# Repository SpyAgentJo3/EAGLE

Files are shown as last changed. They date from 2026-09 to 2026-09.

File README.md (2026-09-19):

# EAGLE
This repository contains all information and project files having to do with EAGLE a system designed for recovery and aerodynamic control of suborbital student rockets. EAGLE contains of a self-developed PCB and the mechanical design for a 16cm diameter rocket 

## Repository Structure

The repository is organized into the following main directories:

```text
├── ARCHER
│   ├── CAD Design
│   ├── Documentation
│   │   ├── Circuit Drawing
│   │   ├── Mechanical Design
│   │   ├── PCB
│   │   └── Software
│   ├── PCB Design
│   │   ├── CanSat Shield - Landesysteme v1.0.0
│   │   ├── EAGLE Recovery v1.0.0
│   │   ├── Footprint Library
│   │   ├── KiCAD 3D Models
│   │   ├── PCB Concept v2.0.0
│   │   └── Symbol Library
│   ├── Pyrochannels
│   ├── Simulation
│   ├── Software
│   │   └── EAGLE v1.2.1
│   │       ├── src
│   │       └── test
│   └── Misc
```

The repository contains the following main areas:

- **CAD Design** – CAD models and mechanical design files
- **Documentation** – Technical documentation, circuit diagrams, PCB documentation, and software-related documentation
- **PCB Design** – PCB layouts, libraries, concepts, recovery versions, and related design files
- **Pyrochannels** – Design files and backups related to the pyrochannel system
- **Simulation** – Simulation models and related files
- **Software** – Source code and tests for the project software
- **Misc** – Additional files that do not belong to the other categories

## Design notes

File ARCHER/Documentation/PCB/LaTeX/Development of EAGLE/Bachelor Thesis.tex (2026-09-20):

\documentclass[fontsize=11pt,%
twoside,% oneside als Alternative m\"{o}glich
BCOR          = 8mm, % bei Bedarf anzupassen
DIV           = 11,  % kann nach Belieben geändert werden
titlepage     = off,%
index=totoc,%
xcolor        = pdftex,%
dvipsnames,%
bibliography  = totoc,%
bibliography = numbered, % bei Bedarf einschalten
listof        = notnumbered]{scrreprt}

\usepackage[left=3.5cm,right=2cm,top=2.5cm,bottom=2cm]{geometry}
\usepackage[english]{babel}                         %deutsches Sprachpacket
\usepackage[utf8]{inputenc}                         %input utf8
\usepackage[official]{eurosym}                      %Symbolsatz
\usepackage{amsmath}                                %Mathepacket
\usepackage{siunitx}                                %Package für zwei nachfolgende Befehle
\sisetup{locale=UK}
\sisetup{per-mode=fraction}
\usepackage{graphicx}                               %Bilder einfügen
\usepackage{subfigure}                              %Subfigures erstellen
\usepackage{subcaption}
\usepackage[onehalfspacing]{setspace}               %für Abstände
\usepackage{booktabs}                               %Für Ruler in Tabellen
\usepackage{makecell}
\usepackage{caption}
\usepackage{tabulary}
\usepackage{tabularx}
\usepackage{array}
\usepackage[table]{xcolor}
\definecolor{light grey}{RGB}{182,182,182}
\usepackage{rotating}
\usepackage{tablefootnote}
\usepackage{refcount}
\usepackage{hhline}
\usepackage{adjustbox}
\usepackage{subcaption}
\usepackage{float}
\usepackage{acronym}
\usepackage{listings}
\definecolor{codegreen}{rgb}{0,0.6,0}
\definecolor{codegrey}{rgb}{0.5,0.5,0.5}
\definecolor{codepurple}{rgb}{0.58,0,0.82}
\definecolor{backcolour}{rgb}{0.95,0.95,0.92}
\definecolor{codeblue}{rgb}{0.0,0.4,0.8}
\lstset{
	language=C++,                       % Sprache auf C++ setzen
	backgroundcolor=\color{backcolour}, % Hintergrundfarbe
	commentstyle=\color{codegreen},    % Farbe für Kommentare (z.B. // )
	keywordstyle=\color{codeblue}\bfseries, % Farbe für Keywords (int, auto, void, ...)
	numberstyle=\tiny\color{codegrey},  % Stil der Zeilennummern
	stringstyle=\color{codepurple},     % Farbe für Strings ("Text")
	basicstyle=\ttfamily\small,         % Festbreitenschriftart für den Code
	breakatwhitespace=false,            
	breaklines=true,                    % Automatische Zeilenumbrüche bei langen Zeilen
	captionpos=b,                       % Beschriftung unter dem Codeblock
	keepspaces=true,                    
	numbers=left,                       % Zeilennummern links anzeigen
	numbersep=5pt,                      % Abstand der Nummern zum Code
	showspaces=false,                
	showstringspaces=false,
	showtabs=false,                  
	tabsize=4,                          % Tabulatorbreite
	frame=single,                       % Rahmen um den Codeblock
	rulecolor=\color{gray!30}           % Farbe des Rahmens
}
\usepackage{accents}
\usepackage[stable]{footmisc}
\usepackage{pdfpages}
\usepackage[
backend=biber,
style=numeric,
sorting=none
]{biblatex}
\DefineBibliographyStrings{english}{
	bibliography = {References}
}
\addbibresource{mybibFile.bib} %Import the bibliography file
\counterwithin{figure}{section}
\counterwithin{table}{section}
\counterwithin{equation}{section}

\begin{document}

\begin{titlepage}
	\centering

	\begin{center}
	\captionsetup{font=footnotesize}
	\begin{figure}[!h]
		\subfigure{}
        \hspace{0.5cm}
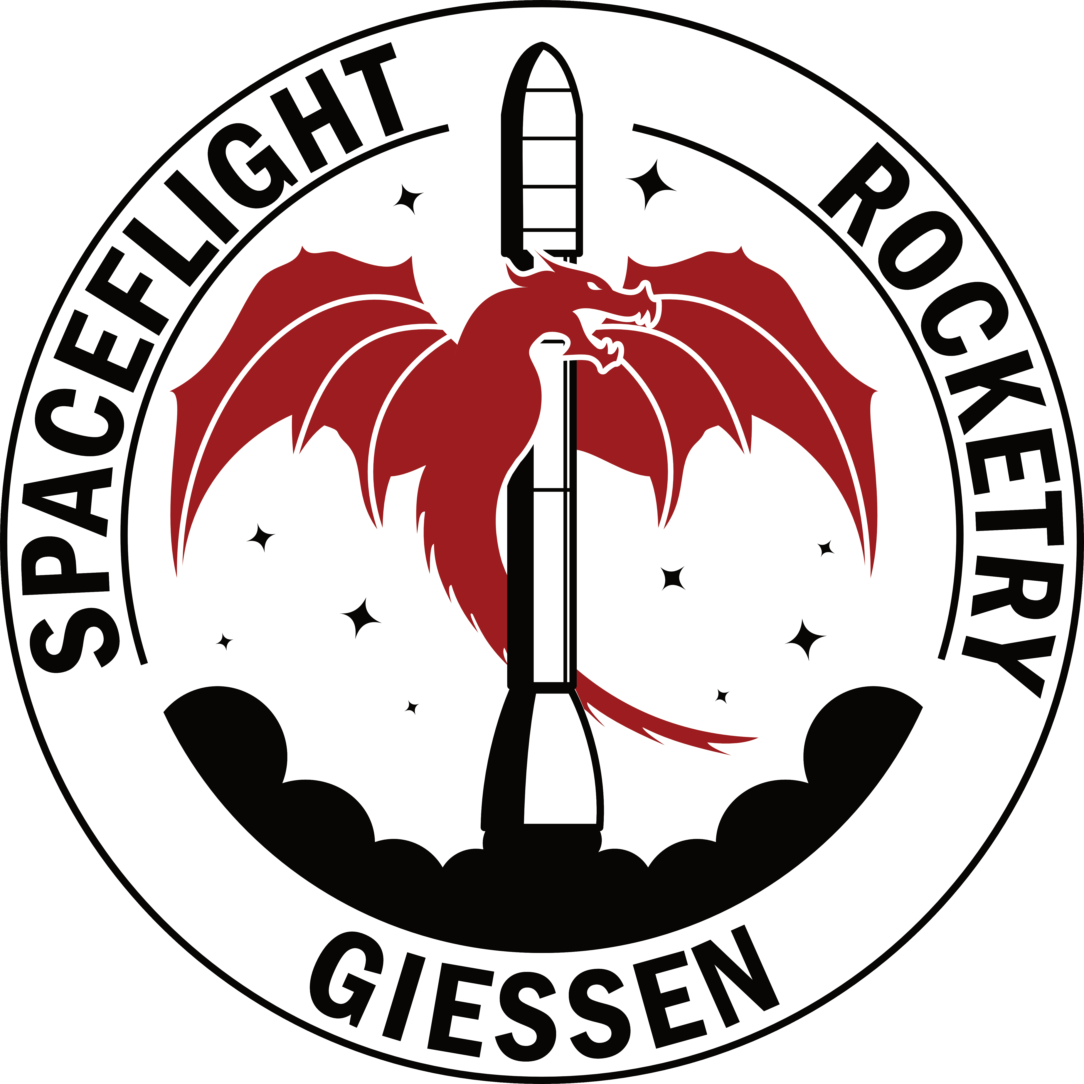
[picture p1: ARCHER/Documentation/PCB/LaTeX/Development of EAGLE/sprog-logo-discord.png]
		\subfigure{}
    \end{figure}
    \end{center}

	{\scshape\LARGE Technische Hochschule Mittelhessen \\ und \\ Spacelfight Rocketry Gießen e.V.\par}
	\vspace{1cm}
	{\scshape\Large Projektarbeit\par}
	\vspace{1cm}
	{\huge\bfseries Development of the Electronic Actuaion \& Guidance for Landing and Elevation (EAGLE) system\par}
	\vspace{0.25cm}
    \rule{\textwidth}{.5pt}
    \vspace{.25cm}
    {\large\bfseries Entwicklung des Electronic Acutation \& Guidance for Landing and Elevation (EAGLE) Systems\par}
    \vspace{.3cm}
	{\Large\scshape SoSe 2025\par}
	\vspace{1cm}
	{\Large \textbf{vorgelegt von}\\ Jason Gläser\par}
	\vfill
	betreut durch\par
    Prof. Dr. Chris Volkmar
	\vfill

% Bottom of the page
	{\large \today\par}
	\cleardoublepage
\end{titlepage}

\setcounter{page}{1}
\pagenumbering{Roman}

\chapter*{Eidesstattliche Erklärung}
Hiermit versichere ich, dass ich die vorliegende Arbeit selbstständig und unter aus
schließlicher Verwendung der angegebenen Literatur und Hilfsmittel erstellt habe. Die
Arbeit wurde bisher in gleicher oder ähnlicher Form keiner anderen Prüfungsbehörde
vorgelegt und nicht veröffentlicht.\\\\

\noindent Ort, Datum: \dotfill \hspace{3mm} Unterschrift: \dotfill 

\newpage

\chapter*{Abstract}
The development of the "Electronic Actuation \& Guidance for Landing and Elevation" (EAGLE) system is a project developed in cooperation with the student rocketry association "Spaceflight Rocketry Gießen e.V." as part of its self-developed on-board computer called "Advances System for Control Electronics, Navigation and Tracking" (ASCENT). Therefore, I would like to thank Spaceflight Rocketry Gießen for giving me the opportunity to pursue the project with their equipment and funding.\\
EAGLE is a avionics module which uses real-time sensor data to accurately estimate the rockets position and attitude as well as detecting mission critical waypoints (such as apogee) to deploy the recovery system, perform the staging and subsequent firing of the sustainer's motor and make real-time decisions about an active aerodynamical airbrake system, which accurately limits the maximum altitude to a preset value.\\
The development process of a printed circuit board for this system according to the rule book provided by the "European Rocketry Challenge" will be the core subject of this project.

\newpage
\tableofcontents
\cleardoublepage

\listoffigures
\cleardoublepage

\listoftables
\cleardoublepage

\chapter*{List of abbreviations}
	\begin{acronym}
		\acro{SRPOG}[SPROG]{\dotfill Spaceflight Rocketry Giessen}
		\acro{eV}[e.V.]{\dotfill eingetragener Verein}
		\acro{EAGLE}[EAGLE]{\dotfill Electronic Acutation \& Guidance for Landing and Eleveation}
		\acro{PIPE}[PIPE]{\dotfill Project for Inital Practical Experimentation}
		\acro{ARCHER}[ARCHER]{\dotfill Aerial Rocket for Competions and High-altitude Experimental Rocketry}
		\acro{PCB}[PCB]{\dotfill Printed Circuit Board}
		\acro{PWM}[PWM]{\dotfill Power Width Modulation}
		\acro{IC}[IC]{\dotfill Integrated circuit}
		\acro{PSU}[PSU]{\dotfill Power supply unit}
		\acro{SMD}[SMD]{\dotfill Surface mounted devices}
		\acro{SPI}[SPI]{\dotfill Serial peripheral interface}
		\acro{I2C}[I2C]{\dotfill Inter-Integrated Circuit}
		\acro{UART}[UART]{\dotfill Universal Asynchronous Receiver-Transmitter}
		\acro{RAM}[RAM]{\dotfill Random access memory}
		\acro{UPDI}[UPDI]{\dotfill Unified Program and Debug Interface}
		\acro{GND}[GND]{\dotfill Ground}
		\acro{ASCENT}[ASCENT]{\dotfill Advanced System for Control Electronics, Navigation and Tracking}
		\acro{EuRoC}[EUROC]{\dotfill European Rocketry Challenge}
		\acro{COTS}[COTS]{\dotfill Commercial Off-The-Shelf}
		\acro{IMU}[IMU]{\dotfill Inertial Measurement Unit}
		\acro{JLU}[JLU]{\dotfill Justus-Liebig-University Giessen}
		\acro{THM}[THM]{\dotfill Technische Hochschule Mittelhessen}
		\acro{OSR}[OSR]{\dotfill Oversampling ratio}
		\acro{MOSFET}[MOSFET]]{\dotfill Metal-oxide-semiconductor field-effect transistor}
		\acro{ST}[ST]]{\dotfill Schmitt Trigger}
	\end{acronym}
	\cleardoublepage

\setcounter{page}{1}
\pagenumbering{arabic}

\chapter{Introduction}
"Spaceflight Rocketry Gießen e.V." is a student-founded and ran rocketry association at the Justus Liebig University and University of Applied Sciences in Giessen, which develops and builds experimental sounding rockets, with which the association wants to compete at international student rocketry competitions such as the "European Rocketry Challenge" (EuRoC) in Portugal.

\section{Motivation}
Most aerospace related study programs consist of mostly mechanical engineering courses. This leads to most german student teams to have a lack of electrical understanding resulting in the use of commercial-of-the-shelf (COTS) avionics modules such as the CATS-Vega, an all-in-one board computer. Due to the study program "Physics and Technology for Space Applications" at Justus Liebig University in Giessen, which heavily focuses on electrical engineering in the context of space exploration, SPROG's avionics team has been its largest team from the beginning. It was therefore decided to develop its own avionics module called "Advanced System for Control Electronics, Navigation and Tracking" (ASCENT), which consisted of modularized PCBs with tasks ranging from telemetry to recovery.\\
After roughly a year of development, SPROG launched its first ever rocket "PIPE" in Karlshöfen near Bremen in August 2024. During the launch campaign, the self-developed avionics, specifically the recovery module, showed major issues which were not observed during testing. This was overlooked mostly due to limited testing ahead of the launch campaign because of time restrictions and lack of funding.\\
Especially in the early phases of a rocketry project, it is important to collect as much data as possible. To ensure this, it is imperative to have a working recovery system to allow for the recovery of the onboard data drives for data analysis. Whilst the telemetry can provide a selected amount of data, the full data set can only be retrieved by actually getting the data drives from the vehicle. To ensure that they do not corrupt or crack, the recovery system has to reliably deploy and slow down the vehicle enough so that the rocket does not break upon landing.\\
In aerospace, reliability is more important than ever, because the launch cadence of companies like SpaceX has far surpassed the mark of one launch per week. Furthermore, there is an inherit risk to rocketry and a free-falling rocket can pose major risk to viewers or personnel on site.\\
Additionally, it was decided to use the next iteration of SPROG's rocket family called ARCHER to aim for the European Rocketry Challenge, which meant that the designs not only had to be improved but also had to be adapted to the rules of EuRoC. This led to the development of ASCENT II, a full redesign of SPROG's first avionics stack.\\
The objective of this thesis, is to outline the design steps and processes taken for the development of ASCENT II's recovery module called "Electronic Acutation \& Guidance for Landing and Eleveation" (EAGLE) whilst staying within the design framework provided by the EuRoC rule book.

\section{ARCHER}
As mentioned before, ARCHER is SPROG's entry for EuRoC. It is a two-staged experimental rocket relying on COTS solid rocket motors as its propulsion system. It will feature a diameter of 160\,mm and mostly be made of carbon fiber tubes and aluminum bulkheads. ARCHER's main objective will be to compete in the 9\,km solid category and achieve an accurate target altitude. For that it will include an airbrake system, which will control its ascent by deploying flaps similar to SpaceX's grid fins.\\
At the core of ARCHER's stages sits the modularized avionics stack called ASCENT II. It will serve as the flight computer, meaning that it will deploy the parachutes for both stages and ignite the second stage motor.\\
ASCENT's design philosophy is based on modules because it makes troubleshooting and expansion of each system easier than having one single avionics board. ASCENT II features a power management system, a sensor module for collecting data, a telemetry module for communication with the ground and EAGLE. The latter deals with parachute deployment, staging, second stage motor ignition and airbrake actuation, all of which are deemed saftey critical systems, because of their potentially dangerous consequences in case of failures.\\

\section{Objectives and scope}
The main objective is the theoretical design of the EAGLE PCB and its software architecture, which should accommodate redundancy of systems and be in compliance with EuRoC rules. However, the testing and use of this PCB and its software will not be featured as part of this report. The main goal is to highlight the processes and architecture of EAGLE in the large context of ASCENT II, showing its design iterations and decision making process.\\
To comply with these objectives, EAGLE will feature a variety of sensors and deal with advanced circuit and software design.

\newpage

\chapter{Theoretical basics}
To illustrate some of the decisions made within the design phase of EAGLE, it is important to first get a basic understanding of the fundamentals of sounding rocket recovery, avionics architecture and PCB design. This chapter deals with said fundamentals and aims to highlight the most important theoretical topics.

\section{Electrical design}
\subsection{Voltage management (RC circuit)}
\subsection{Metal-oxide-semiconductor field-effect transistor (MOSFET)}
\subsection{Inverting Schmitt Trigger}

\section{Software design} 

\subsection{State machines}\label{sec:state_machine}
State machines or Finite State Machine are a commonly used concept in software engineering and generally describes a system which can only be in one state of a finite number of state at a time. It is a event-driven and reactive system which can change its state based on certain events happening or conditions that are met.\\
An example for a state machine would be a video, which can have multiple states such as: Paused, playing, stopped and so on. A possible transition between those states would be something like pressing the pause and play button. Pressing the pause button causes a transition from the state "Playing" to the state "Paused". However, while the video is playing it can not be paused or stopped at the same time.\\
By only having one state be active at a time, it makes both troubleshooting and designing simpler. This is due to the modularization of the software. If a certain state is being executed, it means that if an issue occurs it can only be caused by this specific state. This instantly narrows down the amount of error sources. Additionally, each state can be developed independently as there are no dependencies between states other than the transition conditions. Each state behaves as if it was its own program that is called from a seperate program. It also makes the predictability of a system more reliable, because of the same reason. A smaller program is easier to predict in its behaviour by relying on less complexity and dependencies between systems.\\
The way state machines are typically implemented is by the use of switch-case statements, where each case is representative of a state. Typically, each case or state has its own running loop that executes a certain function, which is executed when its in the right state, e.g. playing the video. Within a loop there would be a breaking condition, e.g. a pause button press event, which would both end the loop and also set the next state, which would then start a different loop.\\
State machines do not need to follow a linear stream of states. It is common that certain conditions or transitions can cause jumps in the state machine leaving entire states behind. Similarly, it can be possible to go back to a former state instead of moving forward.

\subsection{PID controllers}

\section{PCB Design}

\section{Communication protocols}
\subsection{Inter-Integrated Circuit (I2C)}
\subsection{Universal Asynchronous Receiver-Transmitter (UART)}
\subsection{Serial Peripheral Interface (SPI)}
\subsection{Comparison}

\section{Sounding rocket recovery systems}
The term "sounding rocket" refers to a suborbital class rocket, which usually only goes to hundreds of kilometers in altitude in order to reach space and achieve a certain amount of zero gravity. This results in the vehicle falling back down to earth after a short amount of time in space. Every sounding rocket features some form of recovery since a free-falling rocket at speeds much higher than the speed of sound poses too much of a risk for nearby people and personnel. Whilst modern orbital class rockets are either expendable (e.g. Ariane\,6) or recovered using propulsive landing methods (e.g. SpaceX Falcon\,9), sounding rockets usually rely on parachutes. This is due to the fact, that the main goal of sounding rockets is to provide a short time in free-fall or zero gravity for experiments\cite{DLRsoundingRockets}, which could otherwise not be completed within earth's atmosphere. This means that the main goal is to maximize payload capacity and minimize the complexity and cost. This is usually achieved by relying on a "simpler" architecture than bi-liquid rockets, such as hybrid or solid motors. For simplicity, only solid motors will be discussed.\\
A solid motor consists of a mix of the fuel and oxidizer in one solid so called "grain", which is ignited and burns at a more or less constant rate. This results in an uncontrolled thrust-curve which is controller by the motors geometry and chemical composition. This makes a complicated system such as tanks and pressurized systems mostly obsolete, because fuel and oxidizer are both stored in the same space. This vastly reduces wait and space taken up by the propulsion segment. Since it is not possible to control thrust on in a solid booster, the recovery can not be made using propulsive methods, which is why parachutes are used.\\
Most recovery systems consist of more than one parachute, the so called "drogue-parachute" and "main-parachute". The drogue is usually significantly smaller than the main parachute.
For smaller sounding rockets that do not cross into space, the reason for that is that the drogue is usually deployed at/or around apogee to stabilize the rocket (as shown in fig. \ref{fig:trajectory}), position it vertical and start initial deceleration\cite{DelftParachute}. The main parachute is only deployed shortly above the surface. Due to the much bigger surface area of the main parachute, the amount of lift created is substantially higher, resulting in a bigger deceleration and slower descent. However, because of said lift and slower descent, the rocket has more time to drift down range, meaning that it lands further away from the launch pad, which makes the recovery after touchdown much more difficult as there is a bigger potential landing area.\\
When the drogue is deployed, it is usually still attached to a piece of rope that holds it close to the air frame of the rocket and the main parachute. When the main parachute is deployed, said rope is cut or otherwise disconnected and the drogue creates a bigger distance due to its wind resistance. In doing so, it pulls out the main parachute which then inflates and decelerates the rocket to its dedicated landing velocity\cite{DelftParachute}.\\

\begin{figure}[H]
	\centering
	\captionsetup{font=footnotesize}
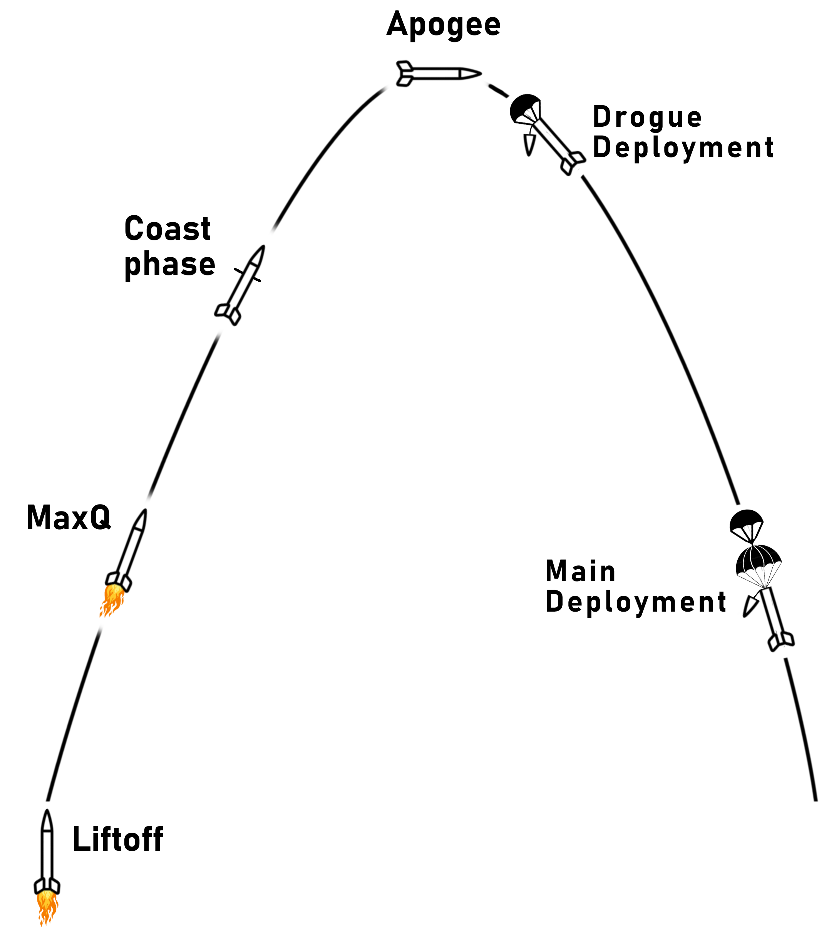
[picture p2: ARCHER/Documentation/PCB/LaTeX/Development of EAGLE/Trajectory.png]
	
	\caption[figure]{Idealized trajectory of a sounding rocket}
	\label{fig:trajectory}
\end{figure}

\section{Flight trajectory\footnote{The following theoretical foundations on the topic of flight trajectories of suborbital rockets are based in part on the author’s previous work from the student project on the topic of the mechanical design of EAGLE (see "Mechanical Design of Electronic Actuation \& Guidance for Landing and Elevation (EAGLE) system"\cite{EAGLE}). This approach is expanded upon below to include the aspects parachute deployment in order to elaborate the milestones which EAGLE will have to be able to autonomously detect}} \label{sec:trajectory}

Because a sounding rocket follows a ballistic, parabolic flight path, its ascent can be divided into a series of distinct phases. Several of these phases mark "milestones" that are directly tied to specific events during flight, such as parachute deployment or the separation of stages in a multi-stage vehicle.\\
Eight milestones are relevant in this context which are shown in figure \ref{fig:trajectory}: Liftoff, MaxQ, booster burnout, the coast phase, apogee, drogue deployment and main parachute deployment. Each is described below.\\
The vehicle experiences its highest g-forces at liftoff, the moment it leaves the launch rail immediately following booster ignition. Because amateur rockets tend to have a very high thrust-to-weight ratio - large upward thrust paired with comparatively little mass - liftoff produces a pronounced jolt that puts considerable strain on the rocket's components. This spike in acceleration can be used to detect liftoff by accessing data from the accelerometer and IMU of the vehicle's avionics system.\\
A short time later, the vehicle reaches its point of maximum dynamic pressure, known as "MaxQ." At this moment, aerodynamic loading on the vehicle peaks, and with it the mechanical stress caused by aerodynamically induced bending moments on the structure - making MaxQ the point of greatest aerodynamic force during the entire flight.\\
Once the motor has burned almost completely, the booster reaches what is called burnout. A small flame may still be visible afterward, as residual propellant continues to burn off, but the thrust it produces at this stage is negligible. What defines burnout, more precisely, is the moment the booster loses the bulk of its thrust, resulting in a acceleration that is similar to earth's gravitation of $\approx9.81\,\frac{\text{m}}{\text{s}^2}$ (relating to the axis perpendicular to the ground), which can serve as indication for autonomous detection of burnout.\\
Between booster burnout and apogee lies the coast phase. No longer driven by the comparatively unpredictable thrust of a solid motor, the vehicle is now governed only by gravity and aerodynamic forces during this stretch of the flight. As a result, its behavior becomes highly deterministic and predictable - making the coast phase the ideal window in which to apply aerodynamic control.\\
The flight culminates at apogee, the highest point of the trajectory and the control setpoint for EAGLE. Vertical velocity falls to nearly $0\,\frac{\text{m}}{\text{s}}$ at this moment, and the rocket transitions into free fall. This point is typically used as a trigger of the deployment mechanism (e.g. pyrotechnic charges) of the drogue parachute.\\
From this point, the rocket falls at a constant speed, which is determined by the size and lift of the drogue parachute. After reaching the target setpoint for main parachute deployment, another mechanism is triggered (e.g. a rope cutter) that causes the drogue parachute to disconnect from the airframe of the rocket such that it only remains connected to the main parachute. This results in the parachute being dragged out and therefore deployed. Afterwards, the rocket glides down at a constant final speed, which will also be the speed with which it touches down on the ground.

\section{Avionics architecture for recovery systems}

\newpage

\chapter{Background and related work}
SPROG is one of many student rocketry teams in Germany alone. However, student rockets and especially the aspect of avionics is not a solved issue. This chaper will highlight the necessity of developing strong and reliable platforms for rocket recovery in the student rocketry sector.

\section{DLR - MORABA}

\section{European student rocketry}

\section{European Rocketry Challenge} \label{sec:euroc}
The "European Rocketry Challenge" (EuRoC) is an international student rocketry competition hosted and organized by the Portugese Space Agency which was first introduced in 2020. Each year a selection of student teams across ESA member states compete in different categories such as altitudes (3 and 9\,km) or propulsion technologies (solid, hybrid and bi-liquid). Especially propulsion technologies get extra attention in the so called "SRAD" (student researched and developed) classed categories as they showcase the innovation and engineering skills of students with limited funding. This competition has pushed teams to challenge the limits of student rocketry by building e.g. the first ever student-built regeneratively cooled bi-liquid engine in Europe by WARR Rocketry.\\
The competition awards multiple winners in different categories. Awards are decided based on the design, team spirit and accuracy regarding the targeted altitude. A team that achieves an apogee close to their target altitude receives more points than a team that is far away.\\
It provides an ideal environment to prove skills under high stress environments for young and aspiring aerospace students whilst also connecting teams from across Europe. The aim is to strengthen Europe's aerospace sector by promoting a connected education program through friendly competitions.

\newpage

\chapter{Requirement Analysis} \label{chap:Requirements}
With ASCENT being SPROG's main flight computer for in-flight decisions during EuRoC, it does not only have to comply with internal requirements, but also external requirements set within the official sytsem design rule book provided by the portugese space agency. Failing to comply with set rules will lead to either a failed launch readiness review ahead of the launch during competition days or exclude any chance of qualification.\\
Additionally, SPROG's own vision on the architecture and redundancy also plays a huge factor. The requirements stated by both parties will be discussed in this chapter.

\section{SPROG's requirements}
Due to the system additions made between PIPE and ARCHER, EAGLE will need to be able to handle a multitude of tasks reliably and accurately. Before even considering an application for EuRoC it was decided that EAGLE would be put in charge of recovery, staging and airbrake control. Since said tasks require strong reliability and accuracy, it was decided that EAGLE itself should be a dual redundant system featuring at least two sources for each data type (e.g. pressure, acceleration, etc.) that would be needed to accurately determine the rockets position and attitude. To achieve this, it was decided to determine the altitude using a processed value of acceleration data (through integration) and barometric pressure (altitude calculation). Furthermore, the acceleration data and barometric altitude estimation could be used to estimate the rockets speed. For this reason, two entirely different pressure sensors and accelerometers were selected. On top of that, an inertial measurement unit (IMU) was selected to provide feedback on the rotation speed of the rocket during ascent and additional acceleration measurements.\\
The recovery team opted for a pyrotechnic charge to deploy the drogue parachute, meaning that EAGLE would need to be able to fire pyrotechnic igniters. During PIPE's launch campaign, it was noted that having the firing electronics external to the PCB leads to a multitude of issues including wiring and space management. That is why the requirement was made to add all electronics having to do with pyrotechnics onto the PCB. Similarly, it was also decided to not use a screw terminal to fixate the igniters, EAGLE will sit in the middle of the avionics stack. This would make replacement of the igniter require a full de-stacking of the avionics system, which is both time consuming and complex. It would therefore be required to be able to replace the igniters in a full stack, meaning that the connector has to be chosen accordingly. The igniters that were chosen also required a current of at least 1\,A to fire. This means EAGLE needs to be able to provide 1\,A on all 4 channels, ideally simultaneously.\\
Additionally, EAGLE needed to be able to provide "power width modulation" (PWM) signals to control the airbrake's servo. However, EAGLE does not need to provide the power to either of these systems. The power needed would be provided by another avionics module according to EAGLE's power requirements. The power provided to each PCB of the stack is limited to 3.3\,V and 5\,V. For the igniters and additional $V_\text{pyro}$ of 12\,V will be provided. Therefore, no component can use more than 5\,V as its supply voltage.

\section{EuRoC system requirements} \label{sec:euroc_rules}
Due to EAGLE wide-range of applications, it becomes necessary to apply multiple requirements set by the organizer's across the following categories:

\begin{itemize}
	\item Ignition systems
	\item Recovery systems and avionics
	\item Active flight control systems
	\item (Trajectory and stability)
\end{itemize}

The latter will not be discussed within this report, as it has already been discussed in an associated project showing the design of the mechanical aspect of EAGLE (i.e. the airbrakes), where such topics have been discussed. On top of that, requirements that do not directly influence the design of EAGLE will not be discussed.

\subsection{Ignition systems}
According to the design requirements ignition systems shall be disarmable and only be armed upon detecting liftoff \cite[p.~16]{EurocRules}. In this case, arming means that there needs to be at least two actions required for any igniter firing. EAGLE pyrotechnic firing channels must therefore be able to be armed both through soft- and hardware.\\
As already specified by SPROG's recovery team, EuRoC also requires an electronic ignition system for all solid rocket motor ignitions \cite[p.~15]{EurocRules}. This implicates that EAGLE requires the before mentioned electronic firing channels.  

\subsection{Recovery Systems and Avionics}
The before mentioned ignition requirements also have some implications for the recovery system and avionics section. EuRoC requires a fully redundant recovery system including seperate flight computers and sensor \cite[p.~24]{EurocRules}, including a COTS flight computer. This also includes all parts involved in the electric firing of pyrotechnic charges. As already discussed, two sensors per data type has already been required by SPROG and has been further confirmed by the organizer's rules.\\
For two staged vehicles, it is mandatory to employ a dual deployment recovery consisting of a drogue and main parachute \cite[p.~28]{EurocRules} for every part of the rocket that is estimated to reach an apogee of more than 450\,m. This paired with a fully redundant pyrotechnic firing channels means that there needs to be at least four channels per stage (2 per parachtue). Additionally, initial deployment should happen "at or near apogee"\cite[p.~28]{EurocRules}, meaning that EAGLE's software will need to utilize the data to accuractely detect apogee. Furthermore, main deployment "shall occur at an altitude no higher than 450\,m above ground level"\cite[p.~29]{EurocRules}. This requires an accurate measurement of the altitude through the software data evaluation.

\subsection{Active flight control systems}
EuRoC limits use of active flight controls of the rocket itself to aerodynamic braking, pitch and roll stability augmentation \cite[p.~45]{EurocRules}. ARCHER utelizes aerodynamic braking and therefore falls under these requirements. Similarly to the recovery, all electronics associated with the controls will have to be fully redundant\cite[p.~47]{EurocRules}, meaning that more than one PWM signal will have to be provided in case of failure of one channel. On top of that, the control system will need to have an adjustable dormant phase, during which the system can not be used\cite[p.~46-47]{EurocRules}, which can be implemented both in software and in hardware (only the software aspect will be discussed).

\iffalse
EAGLE sits at the core of SPROG's future rocket "ARCHER" as part of the improved "ASCENT II" computer. ARCHER is a two-staged experimental rocket relying on COTS solid rocket motors and has a diameter of 160\,mm. The goal for ARCHER is to compete in EuRoC's 9\,km COTS solid category and reach the target altitude as accurately as possible.\\
Due to EuRoC's regulations, EAGLE has to incorporate some system requirements set by the organizers. This means that the initial parachute deployment has to happen "at or near apogee" \cite{EurocAV} meaning that EAGLE has to be able to detect apogee, it needs to be able to accurately detect the current height of the rocket to oblige with other rules such as a rule stating: "The main deployment event shall occur at an altitude no higher than 450 m AGL" \cite{EurocAV}. EAGLE also needs to be able to actuate servos accurately. Furthermore, it needs to be able to fire pyrotechnic charges on multiple so called "pyro-channels". This means that an igniter needs to be externally connected to the PCB. For safety reasons, these pyro-channels should not be able to fire unless armed through a high signal (3.3\,V) coming from an external source. Additionally, the continuity should be measured on these pyro-channels to determine the state of the igniters whilst being vertical on the launch pad. To communicate these igniter states with a ground operator, EAGLE needs to be able to communicate with an external telemetry system.
An optional requirement is to be able to program the microcontroller using an USB type C interface. All systems should be SMD as breakout boards take up a lot of space need to be attached separately by cable leading to extra noise due to vibrations.\\
To achieve this, EAGLE features five sensors including two accelerometers, two pressure sensors and one IMU, which have been decided on based on multiple parameters such as measurement range, resolution, operating voltage and noise level. The microcontroller in charge needs to be able to manage all the data, filter it and make decisions based on the data. In addition to that, there are 4 pyro-channels that allow for a maximum current of 3\,A with an external connection terminal and 6 PWM-channels, which will be used for servo actuation. Everything is based on an internally designed PCB layout that fits our current rocket diameter. \fi

\newpage

\chapter{System Architecture}
It is important to understand the architecture around EAGLE and ASCENT II in order to understand some of the decisions in a bigger context. As shown in chapter \ref{chap:Requirements}, both hard- and software play a crucial part in understanding how EAGLE works and works it (un-)reliable. Therefore, this chapter aims to outline the overall architecture of ASCENT II and EAGLE. In doing so, both the hardware and software will be discussed.

\section{Hardware Architecture}
EAGLE's own hardware is heavily reliant on external inputs from the other avionics modules. Whilst it is as self-reliant as possible, having a fully standalone system defeats both the purpose of redundany as well as a modularized avionics stack. Therefore, it is important to discuss both the overall architecture and the architecture relating to EAGLE itself.

\subsection{ASCENT II Architecture}
ASCENT II consists of four modules: Telemetry, sensor systems, EAGLE/Recovery and the energy management system as shown in figure \ref{fig:ASCENT_architecture}. Each subsystem in the flight computer serves an individual purpose and all components interact with each other. The interaction happens over common communication protocols which are transmitted over standard connectors.

\begin{figure}[H]
	\centering
	
	\caption{ASCENT II architecture}
	\label{fig:ASCENT_architecture}
\end{figure}

At the core of the "active" modules sits the telemetry module which serves as the grandmaster\footnote{Each module has two I2C channels. "Grandmaster" refers to the master of the channel over which the modules communicate with each other, "master" refers to the channel which each module uses "locally" for communcation with e.g. sensors.} in the I2C communication interface. This was chosen since it will be receiving and transmitting all necessary flight data to the ground station as well receive and manage all incoming commands from the ground. It initiates communication with the other modules when it is ready to receive data to be transmitted using so called "interrupts" on the I2C channel. This causes the slave module to interrupt its current software for a very short amount of time to answer the call from the telemetry module. Since the modules run asynchronously\footnote{They run at different loop timings and are not synchronized}, there would otherwise be a chance of packet loss due to overbuffering. This could be caused by one module sending data quicker than the other communication partner can receive/read said data. Additionally, this also avoids the possibility of multiple modules trying to communicate over the same channel at once, which would result in the loss of all packets on the channel, due to the nature of I2C half-duplex architecture. One of the before mentioned commands is the arming signal and the deployment commands. As part of the requirements in chapter \ref{chap:Requirements}, it is necessary to provide more than one step in order to be able to deploy any kind of energetics on the launch pad. Without an active arming signal, which is given by a user-command\footnote{Has to be sent by a human-in-the-loop}, EAGLE is not able to fire any pyro-channel and therefore deploy any parachutes.\\
The sensor modules' primary objective is collecting and logging all the critical flight data that can be used for flight analysis after touchdown. It not only collects data about altitude and internal pressures, but also about the GNSS position and bending loads on the rocket using strain gauges. It also receives essential data about the state of flight from EAGLE using the UART communication protocol so that said data can also be logged. The logging happens on an SD-card as well as a flash chip. The latter being necessary for a hard touchdown as IC's are not prone to cracking under shock, whereas SD-cards can easily crack under shock loads.\\
The battery managements system is ASCENT II's only "passive" module, meaning that there is no software or microcontroller involved. It only utilizes passive elements such as DC-DC voltage converters, capacitors and resistors to execute its function. Its main objective is to down-regulate the incoming 14.8\,V from the battery pack to 3.3\,V and 5\,V, which are then used by the other modules to power things such as microcontrollers and sensors (3.3\,V) and such as the telemtry module (5\,V). On top of that, it smooths out voltage spikes by using a combination of resistors and capacitors.\\
The last of ASCENT II's modules is EAGLE, which controls parachute deployment and airbrake actuations. It also features its own set of sensors in order to make it independent of the sensor modules. This was done, because the only way left to communicate between the two modules was UART (due to lack of I2C channels) or SPI. The latter being considered to complex to be implemented at the time and the other being considered significantly slower than I2C in terms of communication speed, which is not reliable enough for real-time decision making.\\
In total, ASCENT II consists of five PCB's (2 Sensor modules), which are all individually designed along a certain design standard and PCB concept, which will be further discussed in subchapter \ref{sec:PCB_concept}.

\subsection{PCB concept} \label{sec:PCB_concept}
In order to ensure the modularized design and having a consistent designs across all modules, a PCB concept was implemented. The concept, as seen in figure \ref{fig:PCB_concept}, consists of some standard component that should included in every module. One of these components are the two pin connectors on the left and right of the PCB. These are the main connections between the modules and carry signals and voltage supply over common pins. Additionally, there is a programming interface on the bottom left of the top view, which can I either be connected to a commonly used USB to UART converter or a UPDI converter, which can both be used for programming the microcontroller, depending on which protocol it supports. To the right of said interface, there is two status LED's. One of them, is single color LED, whilst the other is a RGB LED. The single color LED can be used to show simple debugging steps, like that the microcontroller is running and executing its software. The RBG LED is supposed to display the status of the module. This could be something like green = running, red = error and other colors indicating what part of the software is being executed. These LED's main purpose is debugging and troubleshooting with visual feedback, which would be crucial during a launch campaign, where any kind of mistake should ideally be caught before final integration.\\
For integration purposes, the PCB also has standardized mounting holes, which can only be mounted in one specific way. That way, no PCB can be mounted incorrectly leading to the pins on the connector to be swapped around. When stacked, the PCB's are connected by the pin connectors and by threaded spacers which screw together through the mounting holes.\\
All of these standard features were either proven during or a learning of SPROG's inaugural launch.

\begin{figure}[H]
	\centering
	\captionsetup{font=footnotesize}
	\subfigure[Top view]{}
	\hfill
	\subfigure[Bottom view]{}
	\caption{PCB concept}
	\label{fig:PCB_concept}
\end{figure}

\subsection{EAGLE Architecture}
EAGLE's architecture, which is shown in figure \ref{fig:EAGLE_architecture} slightly varies from that of the other modules. This comes down to the fact that EAGLE is designed to handle a broader variation of system i.e. airbrakes, parachute deployment and staging. To keep up reliability and minimize the effect of external influences, EAGLE does most of the flight computers tasks independently. This also includes its own set of sensors. The amount of sensors is based on the redundancy requirement in EuRoC's. For this reason, every type of sensor, except for the inertial measurement unit (IMU), has a redundant partner from an entirely different manufacturer. This is done so that no systematic issues of the sensor influence both readings, creating a more robust infrastructure. An IMU collects acceleration data (similar to the accelerometers) but also collects rotation speed. Since there are already two accelerometers, adding another acceleration reading will improve accuracy of the processed signal, but will not have a big impact of overall system reliability. The reason it was still added is purely for its capability to retrieve the rotation speed, which was added in case such a measurement might be needed in the future. In addition to sensors, it became apparent that additional input and output (IO) ports were needed. For this reason a (GP-)IO multiplexer was added, which added another 16 IO's to the already existing IO's of the microcontroller.\\ 
To communicate and process the data from the sensors and multiplexer, EAGLE features its own microcontroller, which uses its secondary I2C port to communicate with the sensors with itself as the master and each sensor as its slave. Furthermore, it communicates with the telemetry module using I2C where it acts as the slave of the grandmaster. If the arming signal was given by the telemetry module, it was possible for the main control unit (MCU) to send a voltage signal to the pyro-channels, which would lead to the firing current to be released. On top of that, the MCU can also send sensing voltages, which would not be high enough to ignite the pyrotechnics, to detect the current running through the system. If it was then able to detect any form of current, it was clear that a pyrotechnic igniter was installed and continuity on the channel was present. The MCU is also capable of sending PWM signals to a servo that would actuate the airbrakes.\\
During the development of ASCENT I, it was discovered that requiring a middle man to decode USB to UART signals in order to program the MCU, was time consuming and complex, because it required you to put both systems on the same power and ground reference, which made programming labour intense. To avoid this, with this iteration, EAGLE features a USB-C interface that includes all features of the USB to UART converter, which would let you read data from the MCU and program it with one interface, without connecting any additional wires.\\
There are also some external connections. These include the before mentioned I2C connection to the grandmaster, with EAGLE acting as its slave. It also includes the arming signal, without EAGLE is physically incapable of firing the pyro-channels. EAGLE also gets its main voltage supply $V_\text{dd}$, a 3.3\,V connection and the supply voltage for the pyrotechnics $V_\text{py}$ from external connections\footnote{Any external connection mentioned in this subchapter refers to connections coming from the pin connectors}. $V_\text{dd}$ and $V_\text{py}$ are then internally routed to the pyro-channels where they are used.

\begin{figure}[H]
	\centering
	
	\caption{EAGLE architecture}
	\label{fig:EAGLE_architecture}
\end{figure}

\section{Software Architecture}
With EAGLE being in charge for many systems that would be considered saftey-critical, it is imperitive that the software is just as reliable as the hardware. Any unexpected behaviour can - in the worst-case scenario - cause a catastrophic failure, which could result in the loss of the rocket or damage to person and property. The overall architecture and decisions that led to this architecture will be highlighted in this subchapter.

\subsection{State machine}
EAGLE's software is based on the concept of a state machine which was introduced in subchapter \ref{sec:state_machine}. The reason it was chosen as the architecture is due to the predictability and simplicity. On top of that, a rockets trajectory can be split into certain milestones or states (as discussed in subchapter \ref{sec:trajectory}). EAGLE's state machine consists of eight states, which are shown in figure \ref{fig:Software_architecture}. The states consist of "Pad idle" (0), "Initialized" (1), "Armed" (2), "Boost phase" (3), "Coasting" (4), "Apogee" (5), "Main deployment" (6), "Landed" (7) and "Abort" (8). Each state is assigned a number as part of an enumeration, which maps number values to strings for easier use in the software. The numbers of each state are represented in parentheses.

\begin{figure}[H]
	\centering
	
	\caption{Software architecture}
	\label{fig:Software_architecture}
\end{figure}

"Pad idle" is the starting state of the state machine. It is the default state that is assumed when EAGLE is powered on. At this stage, communication to the sensors is established by running an "I2C scanner", which sends a handshake (signal) to all 255 possible I2C addresses and waits for a response. If a response is received, communication to the sensor is considered established. Additionally, continuity of the pyro channels is checked. It detects a sensing current going through the pyrotechnic igniters. Detecting the sensing current on the minus port of the pyro channel implicates that the electrical circuit is closed, indicating a connected igniter. Each igniter can be tested individually by cycling through the individual pyro channels. At this point, anything that is off nominal would lead to an abort or recycle. Whilst EAGLE is made of many redundancies, it is unwise to launch with the knowledge that these redundancies have already been used. During this phase the vehicle is still unarmed and can quickly be taken down for inspection, which is why it makes sense to abort the launch should any abnormalities be found.\\
"Initialized" indicates that the microcontroller has successfully established communication with all sensors and peripherals, whilst also confirming that igniters are connected. In this state, the continuity to the igniters is still continuously checked, while waiting for the armed command from the telemetry via I2C.\\
Once the arming has been confirmed EAGLE enters the "Armed" state. In this state only continuity and liftoff detection are being checked for. Similarly to the prior states, any abnormalities on the continuity would result in an abort. Liftoff is detected by using the accelerometer data to detect a spike in acceleration, which would only happen when the booster is producing its main thrust. After liftoff, continuity will no longer be checked as the main objective is no longer to catch abnormalities, but to perform the main flight logic.\\
As already discussed in subchapter \ref{sec:trajectory}, a key characteristic of booster burnout is an acceleration of $\approx9.81\,\frac{\text{m}}{\text{s}^2}$ on the axis perpendicular to the ground. When this is detected, the software enters the coasting phase. During this phase, staging will be initiated (if the rocket is two staged) and the airbrake logic will be executed, because it is the only phase in the ascent, where only gravitation and aerodynamics dictate the flight.\\
The "Apogee" state runs the logic required to deploy the drogue parachute. This is dictated by the EuRoC rules as shown in subchapter \ref{sec:euroc}. At apogee, pyro channel 1 would be set to high igniting the first set of pyro charges. Additionally, there is logic which detects drogue deployment. If drogue deployment is not detected after a certain time, pyro channel 2 will be set to high, to ignite the secondary, redundant pyro charge for the drogue. Even without confirmed deployment, it constantly checks the current altitude versus the setpoint set for main parachute deployment.\\
"Main deployment" is essentially the same as apogee, but it used pyro channel 3 as primary and channel 4 as redundant igniter. Whilst this state follows the pyro state, it is not necessary to have a confirmed drogue deployment in order to try to deploy the main parachute. This is due to the fact, that a false negative on the confirmation is possible and it should not prevent the main parachute from deploying. On top of that, there is no downside to trying to deploy main parachute. Although there are low chances that the main would deploy without the drogue, it is not impossible, so it is reasonable to attempt the deployment.\\
As a last step, the vehicle enters the "Landed" state, which tells the telemetry to un-arm the pyro channels, so the rocket can safely be approached. It also tells the telemetry to initiate recovery procedures such as activating a beeper and power down systems to allow for maximum sending time of the touchdown location.\\
If there are any off nominal reports during the setup process, the "Abort" state may be entered, which tells the operator on the ground to hold the launch. However, this state does not have the capabilities to prevent the launch other than advice the operator to stand down. From an abort state, the telemetry can be used to make a decision whether to recycle the attempt, which means that the state machine would remotely be set back into the "Pad Idle" state by an operator or whether to abort the launch attempt and take the rocket off of the launch rail.

\subsection{State transitions}
Each transition between states is governed by one or more boolean trigger conditions derived from sensor readings and system checks. Table \ref{tab:setup_state_transitions} and table \ref{tab:flight_state_transitions} specify these conditions for the setup phase and flight phase, respectively. Within these tables, a dash ("–") denotes a don't-care condition: the corresponding flag has no influence on whether the transition occurs, and may hold either value.\\
Following power-up, the system resides in the initial setup/pad idle state (0). If both the sensors established and continuity flags evaluate to TRUE, initialization is considered complete and the system transitions to the initialized state (1), independent of the armed flag's state at that point. Conversely, if both flags are FALSE, setup is deemed to have failed and the system transitions directly to the abort state (8).\\
From state 1, the system remains unarmed as long as continuity is maintained and the armed flag is FALSE (transition $1\rightarrow1$). If the armed flag becomes TRUE while continuity is still present, the system transitions to the armed state (2). Should continuity be lost at any point while in state 1, the system transitions to the abort state (8), regardless of the other flags.\\
State 2 behaves analogously with respect to continuity: the system remains in state 2 as long as continuity is present ($2\rightarrow2$), and transitions to the abort state (8) if continuity is lost.\\
Once setup completes successfully, the system enters the armed state (2), from which it transitions to the boost state (3) upon detection of liftoff. (As shown in table \ref{tab:flight_state_transitions}, state 2 additionally reverts to the abort state (8) if continuity is lost prior to liftoff).
If the system enters an abort state, an operator on the ground may decide to abort the launch attempt or to recycle the state machine, forcing it back into the pad idle state, from where operations would start over again.\\
After detecting liftoff, the system monitors for booster burnout, apogee and main deployment. Each variable can lead to a different transition, as it is possible that either one of these steps is missed. However, it is important that EAGLE remains capable of deploying parachutes even if one or more events have been missed. For that reason, detecting apogee or main deployment altitude, would result in the state transition into the apogee ($3\rightarrow5$) or main deployment ($3\rightarrow6$) state. If the event monitoring is nominal, the coasting phase ($3\rightarrow4$) would be entered. Im the off-nominal case, the coasting phase would be skipped and all airbrake actuation would not be executed. This is done to ensure EAGLE's main objective, which is the successful and safe recovery of the rocket.\\
Analogous to the boost state, the system can jump into multiple outcomes, in this case into apogee ($4\rightarrow5$) and into main deployment ($4\rightarrow6$). This is done for the same reason of being able to control the parachutes even if an event has failed to get noticed.\\
When in the apogee state, the state machine has the nominal case of detecting main deployment ($5\rightarrow6$). However, there is still a chance that such an event would be missed, in which case the rocket would fall to the ground under drogue parachute, which would cause a relatively high impact speed. In this case, the rocket still needs to be able to inert (unarm) itself, if it survived the impact and therefore needs to be able to detect the landing, which would cause a transition into the landed state ($5\rightarrow7$).\\
If the vehicle does deploy the main parachute or at least enters state 6, it can only transition into landed as it is the last step in the flight sequence of events.\\
The events "apogee detected", "main parachute altitude detected" and "landing detected" can each be redundantly triggered by a ground operator command or by timeout. When EAGLE detects liftoff it starts timers which evaluate if an event could have been reached based on timings from simulations. So even if EAGLE was to not detect apogee or main deployment and still managed to survive the impact, a timer would cause the rocket to inert itself. Similarly, this serves as backup for missed apogee detecting by the sensor values.\\

\subsection{PID Controllers}

\subsection{Internal data processing}

\subsection{Implementation}
Similarly to the state machine, the software is split into a main function and a setup code. The key difference is that the setup code is only called once, whereas the main function is a loop as seen in the code example \ref{code:top_level} . This is part of the arduino framework which was chosen for this project because of its wide range of open-source libraries, which could be used for reading sensors or communicating via UART or I2C.\\

\begin{lstlisting}[caption={Top level code design}, label={code:top_level}]
void setup{
	//runs setup state machine	
	if(liftoff detected && continuity detected)
		state = boost; //start main loop
}
int main {
	while(state != landed){
		//runs flight state machine
		if(execution time > set execution time)
			skip.to.next.iteration;
	}
}
\end{lstlisting}

Because of the time critical nature of the system, it is important that the software runs deterministic i.e. that it runs its main loop in a pre-defined amount of time. This is important, to avoid unexpected behavior. This can be enforced by e.g. using interrupts, which completely stops the loop iteration if this set amount of time has been exceeded. The time for the loop to finish is set by creating a statistic about how long the loop takes to run once over multiple iterations, but can also be pre-defined as a requirement. In this case, it was decided to base it on the average execution time, because whilst it is important to have a deterministic code, parachute deployment may happen within the vicinity of apogee and the main deployment altitude as discussed in subchapter \ref{sec:euroc_rules}.\\

The implementation of the state machine is done by using an enumeration, a list of string values that are assigned to numbers, for abstracting the states, which in turn makes the code more readable. In the main loop, a switch-case statement, essentially a large number of if-else-statements, is executed in every iteration (as shown in code example \ref{code:state_machine}). The main loop only starts executing logic, once the setup process is complete, liftoff was detected and the state has been changed to "boost". The switch-case statement checks which state is currently active and only executes that specific state's logic.

\begin{lstlisting}[caption={States enumeration}, label={code:enum}]
enum States {
	pad_idle = 0,
	initialized = 1,
	armed = 2,
	boost = 3,
	coast = 4,
	apogee = 5,
	main_deploy = 6,
	landed = 8
};
\end{lstlisting}

\begin{lstlisting}[caption={Flight state machine}, label={code:state_machine}]
while(state != landed){
	getSensorData(); //retrievs sensor data
	switch(state) {
		case boost:
			//execute burnout monitoring
			break;
		case coast:
			//execute airbrake and staging logic
			break;
		case apogee:
			//execute drogue deployment logic
			break;
		case main_deploy:
			//execute main deployment logic
			break;
		case landed:
			//execute post-touchdown/inerting logic
			break;
		default:
			//do nothing until a known state is set by the setup state 
			//machine
	}
}
\end{lstlisting}

In each state, outputs are set and the state transition triggers are evaluated. If a transition trigger is detected, the global state variable "state" (can be changed and accessed by all functions) is changed and the respective case is executed. A check for a state transition trigger can look like the following:

\begin{lstlisting}[caption={State transition logic}, label={code:state_transition}]
switch(state) {
	case boost:
	//boost state logic
	if(burnout detected)
		state = burnout;
	break;
\end{lstlisting}

Because of the break statement, the switch-case statement finishes for this iteration and will assume the burnout state in the next iteration.\\
In order to be able to process data within each case, sensor data has to be retrieved. This is done, before calling the switch-case statement, because every state needs the sensor data and it therefore makes the code more readable. In this sensor reading function, all 5 sensors are called and read. Afterwards, the data gotten from these sensors is processed using common data filters to narrow down the error in data calculations. On top of that, multiple sources of the same data will be calculated into one single data point, so that the case only has to call the processed data and does not have to do any advanced arithmetics.

\newpage

\chapter{Preliminary design phase}
Based on prior experience at SPROG, it was decided that each system would need to go through a preliminary design phase during which the requirement and architecture that were defined were to be tested for feasibility. This is done, to ensure that no resources are lost to small mistakes, which were not detected, because of a lack of knowledge or experience. This was an issue that poised SPROG's early stage developments. During the development of ASCENT I, PCB's were designed and ordered early on with minor to major design flaws costing the association time and resources, which were limited during that time due to the young age of the group. This phase was mostly about understanding and selecting the correct sensors and confirm the design on basic open questions. For example, the sensor module phased the question whether to use a built in antenna for the GNSS module or an external antenna. The only relevant open question during this phase was the selection of sensors. The process that were taken to limit the amount of unknowns in the PCB design phase, will be illuminated in this chapter.

\section{Process}
The first step in the preliminary design phase is the selection of components. The requirements dictate the amount of sensors and overall architecture but not which components to use exactly. Therefore, the first major step is to decide on the sensors that were to be used. However, there is no final decisions at this point. This is because each selected sensor had to go through initial testing on breakout boards and had to match certain expectations, which were evaluated during this process.

\section{Component selection}
The requirements and the consequent architecture required five sensors in total: Two accelerometers, two pressure sensor and one inertial measurement unit (IMU) to detect all data necessary for EAGLE's operation. To decide 

\section{Component evaluation}

\chapter{PCB Design - CanSat version}

\section{Design Evaluation and Revision}

\newpage

\chapter{PCB Design - ASCENT II}

\newpage

\chapter{Verification and Testing}

\newpage

\chapter{Discussion}

\iffalse
\chapter{Selection of components}
The components of the PCB make up the most integral part of this system as all decisions and signals are relying on high quality data with low noise. Therefore, a significant amount time was spent researching a multitude of sensors and other components. As mentioned in, the board will feature five sensors and a microcontroller powerful enough to handle all the data. The most important requirements for these is an operating voltage of either 3.3V or 5V as that is the voltage that is being supplied by the PSU.

\section{Microcontroller}
The microcontroller is the heart of all operations and needs to be the most reliable component on the PCB. It collects all the data from the sensors and distributes it to the telemetry system and data storage as well as fire pyro-channels and actuate the servos and be able to read analogue signals. Therefore, the selected microcontroller needs a wide range of pin-types.

\subsection{AVR128DB64}
The AVR128DB64 was the first choice solely based on past experience and ease of programming. It has an easy to understand pinout and 64 pins and runs on the arduino framework. The AVR128DB28 (same family of controllers) has been used in a previous telemetry system meaning there was a lot of experience using this type of microcontroller. Additionally, it allows communication via SPI, UART and I2C (commonly used communication protocols). The latter being used for communication with all sensors and between the communication with the telemetry subsystem. It also featured a relatively new programming protocol called "UPDI", which only requires one pin for programming instead of two dedicated UART ports like other microcontrollers, making programming substantially easier.\\
In hindsight, there should have been less emphasize on past experiences as they allowed for an oversight on the computing power of the chip, which is arguable the most important characteristic. After connecting and testing multiple sensors to the microcontroller, it was discovered the RAM overflowed with data during the first loop, rendering the microcontroller useless for usage in EAGLE.

\subsection{ESP32-S3-Vroom-N4-1u}
After running into issues with the AVR128DB64 a team member of the electronics working group within the association suggested to test the ESP32 as it is a dual-core microcontroller and has more RAM available. It also features all common communication protocols, but needs to be programmed using UART, rendering two pins unusable for any other purposes. The programming also needs to additional pins called "EN" and "IO0" which need to be pulled to GND in a specific sequence to put the microcontroller into the so called "programming mode". However, it did feature a D+ and D- pin meaning a USB interface can easily be connected for programming and data-reading. In addition to that, it is an IC meaning that it has additional features such as an built-in WiFi module and antenna. To save space it was decided to use the "-1u" version, because that means that the ESP32 would come without an antenna but with a coax-connector. However, all of this came at the cost of the arduino framework as ESP32s run on their own firmware and framework. In some cases however, the ESP32 is capable of running arduino code, meaning that the code only needs to be adapted slightly.\\
For those reasons, the ESP32-S3-Vroom-N4-1u was chosen as the microcontroller for EAGLE.
\fi

\newpage
\printbibliography %Prints bibliography

\setcounter{page}{1}
\pagenumbering{Roman}
\chapter{Appendix}

\section{Tables}

\subsection{State transition truth tables} \label{adx:State_transitions}

\begin{table}[H]
	\captionof{table}{EAGLE setup state transitions}	
	\label{tab:setup_state_transitions}
	\centering
	\begin{tabular}{|c|l||c|c|c|c|} \hline		
		\multicolumn{2}{|c||}{\textbf{Transition description}} & \multicolumn{4}{c|}{\textbf{Transition trigger}}\\ \hline
		\textbf{Transition} & \textbf{Cause} & \textbf{Sensors established} & \textbf{Continuity} & \textbf{Armed} & \textbf{Recycle} \\ \hline \hline
		$0\rightarrow1$ & Initialization complete & TRUE & TRUE & -\tablefootnote{"-" means that the state of this flag is unimportant for the transition trigger} & FALSE\\ \hline
		$0\rightarrow8$ & Setup failed & FALSE & FALSE & - & FALSE \\ \hline
		$1\rightarrow1$ & No change & - & TRUE & FALSE & FALSE \\ \hline
		$1\rightarrow2$ & Armed signal & - & TRUE & TRUE & FALSE \\ \hline
		$1\rightarrow8$ & No continuity & - & FALSE & - & FALSE \\ \hline
		$2\rightarrow2$ & No change & - & TRUE & FALSE & FALSE \\ \hline
		$2\rightarrow8$ & No continuity & FALSE & - & - & FALSE \\ \hline
		$8\rightarrow0$ & Recycle command & - & - & - & TRUE \\ \hline
	\end{tabular}
\end{table}
	
\begin{sidewaystable}
	\captionof{table}{EAGLE flight state transitions}	
	\label{tab:flight_state_transitions}
	\centering
		\begin{tabular}{|c|l||c|c|c|c|c|} \hline
			\multicolumn{2}{|c||}{\textbf{Transition description}} & \multicolumn{5}{c|}{\textbf{Transition trigger}}\\ \hline
			\textbf{Transition} & \textbf{Cause} & \textbf{Liftoff detected} & \textbf{Burnout detected} & \textbf{Apogee detected} & \makecell{\textbf{Main deploy}\\ \textbf{setpoint detected}} & \textbf{Landing detected} \\ \hline \hline
			$2\rightarrow3$ & Liftoff detected & TRUE & - & - & - & - \\ \hline
			$3\rightarrow3$ & No change & - & FALSE & - & - & - \\ \hline
			$3\rightarrow4$ & Burnout detected & - & TRUE & - & - & - \\ \hline
			$3\rightarrow5$ & Apogee detected & - & - & TRUE & FALSE & - \\ \hline
			$3\rightarrow6$ & Main deploy setpoint detected & - & - & FALSE & TRUE & - \\ \hline
			$4\rightarrow4$ & No change & - & - & FALSE & FALSE & -\\ \hline
			$4\rightarrow5$ & Apogee detected & - & - & TRUE & - & -\\ \hline
			$4\rightarrow6$ & Main deploy setpoint detected & - & - & FALSE & TRUE & -\\ \hline
			$5\rightarrow5$ & No change & - & - & - & FALSE & -\\ \hline
			$5\rightarrow6$ & Main deploy setpoint detected & - & - & - & TRUE & - \\ \hline
			$6\rightarrow6$ & No change & - & - & - & - & FALSE\\ \hline
			$6\rightarrow7$ & Landing detected & - & - & - & - & TRUE\\ \hline
		\end{tabular}
\end{sidewaystable}

\newpage

\subsection{Sensor characteristics}

\begin{center}
	\captionof{table}{Inertial Measurement Unit(IMU) characteristics Nr.1}	
	\label{tab:sensor_imu1}
	\begin{adjustbox}{width=1.15\textwidth}		 
		\begin{tabular}{|r||c|c|c|c|c||c|c|c|c|} \hline		
			& \multicolumn{5}{c||}{\textbf{BMI160}} & \multicolumn{4}{c|}{\textbf{MPU6500}}\\ \hline
			
			\rowcolor{light grey} $Accelerometer Specs$ & \multicolumn{5}{c}{} & \multicolumn{4}{c}{} \\ \hline \hline
			
			\textbf{Measurement Range} & 2\,g & 4\,g & 8\,g & \multicolumn{2}{c||}{16\,g}& 2\,g & 4\,g & 8\,g & 16\,g\\ \hline
			
			\textbf{Output Resolution} & \multicolumn{5}{c||}{16\,bits} & \multicolumn{4}{c|}{16\,bits}\\ \hline
			
			\textbf{Sensitivity} (Typical) & 16384\,$\frac{\text{LSB}}{\text{g}}$ & 8912\,$\frac{\text{LSB}}{\text{g}}$ & 4096\,$\frac{\text{LSB}}{\text{g}}$ & \multicolumn{2}{c||}{2048\,$\frac{\text{LSB}}{\text{g}}$} & 16384\,$\frac{\text{LSB}}{\text{g}}$ & 8192\,$\frac{\text{LSB}}{\text{g}}$ & 4096\,$\frac{\text{LSB}}{\text{g}}$ & 2048\,$\frac{\text{LSB}}{\text{g}}$\\ \hline
			
			\multirowcell{2}{\shortstack[r]{\textbf{Sensitivity change}\\ \textbf{due to temperature}}} & \textbf{x} & \multicolumn{2}{c|}{\textbf{y}} & \multicolumn{2}{c||}{\textbf{z}} & \textbf{x} & \multicolumn{2}{c|}{\textbf{y}} & \textbf{z}\\ \cline{2-10}
			
			& \multicolumn{5}{c||}{$\pm0.03\,\frac{\%}{\text{°\text{C}}}$} & \multicolumn{4}{c|}{$\pm0.026\,\frac{\%}{\text{°\text{C}}}$}\\ \hline
			
			\textbf{0g Offset} & \multicolumn{5}{c||}{$\pm0.04\,\text{g}$} & \multicolumn{4}{c|}{$\pm0.06\,\text{g}$}\\ \hline
			
			\textbf{Noise} & \multicolumn{5}{c||}{$\pm1.8\,\text{mg-rms}$} & \multicolumn{4}{c|}{Low Noise Mode: $\pm300\,\frac{\text{\textmu g}}{\sqrt{\textbf{Hz}}}$}\\ \hline
			
			\multirowcell{2}{\textbf{Operating Voltage} $V_\text{s}$/$V_\text{DD}$} & \textbf{Min} & \multicolumn{3}{c|}{\textbf{Typical}} & \textbf{Max} & \textbf{Min} & \multicolumn{2}{c|}{\textbf{Typical}} & \textbf{Max}\\ \cline{2-10}
			
			& 1.71\,V & \multicolumn{3}{c|}{3.0\,V} & 3.6\,V & 1.71\,V & \multicolumn{2}{c|}{1.8\,V} & 3.45\,V\\ \hline
			
			\textbf{Interface Voltage} $V_\textbf{DDIO}$ & 1.2\,V & \multicolumn{3}{c|}{2.4\,V} & 3.6\,V & 1.71\,V & \multicolumn{2}{c|}{1.8\,V} & 3.45\,V\\ \hline
			
			\multirowcell{2}{\textbf{Output Data Rate} (ODR)} & \multicolumn{2}{c|}{\textbf{Min}}& \multicolumn{3}{c||}{\textbf{Max}} & \multicolumn{2}{c|}{\textbf{Min}}& \multicolumn{2}{c|}{\textbf{Max}}\\ \cline{2-10}
			
			& \multicolumn{2}{c|}{12.5\,Hz} & \multicolumn{3}{c||}{1600\,Hz} & \multicolumn{2}{c|}{4\,Hz} & \multicolumn{2}{c|}{4000\,Hz}\\ \hline
			
			\multirowcell{2}{\textbf{Current Consumption}} & \multicolumn{2}{c|}{\textbf{Accelerometer}} & \textbf{Gyroscope} & \textbf{Both}(On) & \textbf{None}(Stby) & \textbf{Accelerometer} & \textbf{Gyroscope} & \textbf{Both}(On) & \textbf{None}(Stby)\\ \cline{2-10}
			
			& \multicolumn{2}{c|}{300\,\textmu A} & 900\,\textmu A & 990,\textmu & 10\,\textmu A & 0.45\,mA & 3.2\,mA & 3.4\,mA & 1.6\,mA\\ \hline
			
			\multirowcell{2}{\textbf{Power Consumption}} & \multicolumn{5}{c||}{\textbf{For Typical $V_\text{DD}=3.0\,$V}} & \multicolumn{4}{c|}{\textbf{For Typical $V_\text{DD}=1.88\,$V}}\\ \cline{2-10}
			
			& \multicolumn{2}{c|}{0.90\,mW} & 2.70\,mW & 2.97\,mW & 0.03\,mW & 0.81\,mW & 5.76\,mW & 6.12\,mW & 2.88\,mW\\ \hline
			
			\textbf{Temperature Range} & \multicolumn{5}{c||}{-40\,...\,+85\,°C} & \multicolumn{4}{c||}{-40\,...\,+85\,°C}\\ \hline\hline 
			
			\rowcolor{light grey} $Gyro Specs$ & \multicolumn{9}{c||}{}\\ \hline\hline
			
			\textbf{Measurement Range} & 125\,$\frac{\text{deg}}{\text{s}}$ & 250\,$\frac{\text{deg}}{\text{s}}$ & 500\,$\frac{\text{deg}}{\text{s}}$ & 1000\,$\frac{\text{deg}}{\text{s}}$ & 2000\,$\frac{\text{deg}}{\text{s}}$ & 250\,$\frac{\text{deg}}{\text{s}}$ & 500\,$\frac{\text{deg}}{\text{s}}$ & 1000\,$\frac{\text{deg}}{\text{s}}$ & 2000\,$\frac{\text{deg}}{\text{s}}$\\ \hline
			
			\textbf{Sensitivity} & 262.4\,$\frac{\text{LSB}}{\frac{\text{deg}}{\text{s}}}$ & 131.2\,$\frac{\text{LSB}}{\frac{\text{deg}}{\text{s}}}$ & 65.6\,$\frac{\text{LSB}}{\frac{\text{deg}}{\text{s}}}$ & 32.8\,$\frac{\text{LSB}}{\frac{\text{deg}}{\text{s}}}$ & 16.4\,$\frac{\text{LSB}}{\frac{\text{deg}}{\text{s}}}$ & 131\,$\frac{\text{LSB}}{\frac{\text{deg}}{\text{s}}}$ & 65.5\,$\frac{\text{LSB}}{\frac{\text{deg}}{\text{s}}}$ & 32.4\,$\frac{\text{LSB}}{\frac{\text{deg}}{\text{s}}}$ & 16.4\,$\frac{\text{LSB}}{\frac{\text{deg}}{\text{s}}}$\\ \hline
			
			\makecell{\textbf{Sensitivity Change}\\\textbf{Due to temperature}} & \multicolumn{5}{c||}{$\pm0.02\,\frac{\%}{°\text{C}}$} & \multicolumn{4}{c|}{$\pm3\,\%$\tablefootnote[1]{maximum absolute offset}} \\ \hline
			
			\textbf{Zero-rate Offset} & \multicolumn{5}{c||}{$\pm3\frac{\text{deg}}{\text{s}}$} & \multicolumn{4}{c|}{$\pm5\frac{\text{deg}}{\text{s}}$} \\ \hline
			
			\textbf{Noise} & \multicolumn{5}{c||}{$0.07\frac{\text{deg}}{\text{s}}$-rms} & \multicolumn{4}{c|}{$\pm0.01\frac{\text{deg}}{\text{s}}$-rms} \\ \hline
		\end{tabular}
	\end{adjustbox}
\end{center}

\begin{sidewaystable}
	\captionof{table}{Inertial Measurement Unit(IMU) characteristics Nr.2}	
	\label{tab:sensor_imu2}
	\begin{adjustbox}{width=1.05\textwidth}		 
		\begin{tabular}{|r||c|c|c|c|c|c|c|c||c|c|c|c|c|c|c|c|c|} \hline		
			& \multicolumn{8}{c||}{\textbf{BMI160}} & \multicolumn{9}{c|}{\textbf{MPU6500}}\\ \hline
			
			\rowcolor{light grey} $Accelerometer Specs$ & \multicolumn{17}{c|}{}\\ \hline \hline
			
			\textbf{Measurement Range} & \multicolumn{2}{c|}{2\,g} & \multicolumn{2}{c|}{4\,g} & \multicolumn{2}{c|}{8\,g} & \multicolumn{2}{c||}{16\,g} & \multicolumn{2}{c|}{2\,g} & \multicolumn{2}{c|}{4\,g} & \multicolumn{2}{c|}{8\,g} & \multicolumn{2}{c|}{16\,g} & 32\,g\\ \hline
			
			\textbf{Output Resolution} & \multicolumn{8}{c||}{16\,bits} & \multicolumn{9}{c|}{16\,bits}\\ \hline
			
			\textbf{Sensitivity} (Typical) & \multicolumn{2}{c|}{16384\,$\frac{\text{LSB}}{\text{g}}$} & \multicolumn{2}{c|}{8912\,$\frac{\text{LSB}}{\text{g}}$} & \multicolumn{2}{c|}{4096\,$\frac{\text{LSB}}{\text{g}}$} & \multicolumn{2}{c||}{2048\,$\frac{\text{LSB}}{\text{g}}$} & \multicolumn{2}{c|}{16384\,$\frac{\text{LSB}}{\text{g}}$} & \multicolumn{2}{c|}{8192\,$\frac{\text{LSB}}{\text{g}}$} & \multicolumn{2}{c|}{4096\,$\frac{\text{LSB}}{\text{g}}$} & \multicolumn{2}{c|}{2048\,$\frac{\text{LSB}}{\text{g}}$} & 1024\,g\\ \hline
			
			\shortstack[r]{\textbf{Sensitivity change} \\ \textbf{due to temperature}} & \multicolumn{8}{c||}{$\pm0.005\,\frac{\%}{\text{°C}}$} & \multicolumn{9}{c|}{$\pm0.01\,\frac{\%}{\text{°C}}$} \\ \hline
			
			\textbf{0g Offset} & \multicolumn{8}{c||}{$\pm20$\,mg} & \multicolumn{9}{c|}{$\pm10$\,mg} \\ \hline
			
			\multirowcell{2}{\textbf{Noise}} & \multicolumn{4}{c|}{\textbf{x and y-axis}} & \multicolumn{4}{c||}{\textbf{z-axis}} & \multicolumn{9}{c|}{\textbf{All axis}} \\ \hline
			
			& \multicolumn{4}{c|}{0.65\,mg-rms} & \multicolumn{4}{c||}{0.70\,mg-rms} & \multicolumn{6}{c|}{0.70\,mg-rms} & \multicolumn{2}{c|}{0.80\,mg-rms} & 1.1\,mg-rms \\ \hline
			
			\multirowcell{2}{\textbf{Operating Voltage} $V_\text{s}$/$V_\text{DD}$} & \multicolumn{2}{c|}{\textbf{Min}} & \multicolumn{4}{c|}{\textbf{Typical}} & \multicolumn{2}{c||}{\textbf{Max}} & \multicolumn{2}{c|}{\textbf{Min}} & \multicolumn{4}{c|}{\textbf{Typical}} & \multicolumn{3}{c|}{\textbf{Max}}\\ \cline{2-18}
			
			& \multicolumn{2}{c|}{1.71\,V} & \multicolumn{4}{c|}{1,8\,V} & \multicolumn{2}{c||}{3.6\,V} & \multicolumn{2}{c|}{1.71\,V} & \multicolumn{4}{c|}{1.8\,V} & \multicolumn{3}{c|}{3.6\,V}\\ \hline
			
			\textbf{Interface Voltage} $V_\textbf{DDIO}$ & \multicolumn{2}{c|}{1.71\,V} & \multicolumn{4}{c|}{1,8\,V} & \multicolumn{2}{c||}{3.6\,V} & \multicolumn{2}{c|}{1.08\,V} & \multicolumn{4}{c|}{1.8\,V} & \multicolumn{3}{c|}{3.6\,V}\\ \hline
			
			\multirowcell{2}{\textbf{Output Data Rate} (ODR)} & \multicolumn{4}{c|}{\textbf{Min}}& \multicolumn{4}{c||}{\textbf{Max}} & \multicolumn{4}{c|}{\textbf{Low Noise Mode} (LNM)}& \multicolumn{5}{c|}{\textbf{Low Power Mode} (LPM)}\\ \cline{2-18}
			
			& \multicolumn{4}{c|}{1.5625\,Hz} & \multicolumn{4}{c||}{32000\,Hz} & \multicolumn{2}{c|}{\textbf{Min:} 12.5\,Hz} & \multicolumn{2}{c|}{\textbf{Max:} 6400\,Hz} & \multicolumn{2}{c|}{\textbf{Min:} 1.5625\,Hz} & \multicolumn{3}{c|}{\textbf{Max:} 400\,Hz}\\ \hline
			
			\multirowcell{2}{\textbf{Current Consumption}} & \multicolumn{2}{c|}{\textbf{3-Axis Accel.}} & \multicolumn{2}{c|}{\textbf{3-Axis Gyro}} & \multicolumn{2}{c|}{\textbf{6-Axis Accel. + Gyro}} & \multicolumn{2}{c||}{\textbf{Sleep Mode}} & \multicolumn{2}{c|}{\textbf{6-Axis Accel. + Gyro}\tablefootnote[2]{At 50\,Hz ODR\label{note:50_ODR}}} & \textbf{3-Axis Accel.}\footref{note:50_ODR} & \textbf{3-Axis Gyro}\footref{note:50_ODR} & \multicolumn{2}{c|}{\textbf{6-Axis Accel. + Gyro}\tablefootnote[3]{At 200\,Hz ODR\label{note:200_ODR}}} & \textbf{3-Axis Accel.}\footref{note:200_ODR} & \textbf{3-Axis Gyro}\footref{note:200_ODR} & \textbf{Sleep Mode}\\ \cline{2-18}
			
			& \multicolumn{2}{c|}{0.28\,mA} & \multicolumn{2}{c|}{0.73\,mA} & \multicolumn{2}{c|}{0.88\,mA} & \multicolumn{2}{c||}{0.75\,\textmu A} & \multicolumn{2}{c|}{420\,\textmu A} & 120\,\textmu A & 360\,\textmu A & \multicolumn{2}{c|}{220\,\textmu A} & 67\,\textmu A & 210\,\textmu A & 2.2\,\textmu A \\ \hline
			
			\multirowcell{2}{\textbf{Power Consumption}} & \multicolumn{8}{c||}{\textbf{For $V_\text{DD}=3.3\,$V}} & \multicolumn{9}{c|}{\textbf{For $V_\text{DD}=3.3\,$V}}\\ \cline{2-18}
			
			& \multicolumn{2}{c|}{0.924\,mW} & \multicolumn{2}{c|}{2.409\,mW} & \multicolumn{2}{c|}{2.904\,mW} & \multicolumn{2}{c||}{24.75\,\textmu W} & \multicolumn{2}{c|}{1,386\,mW} & 396\,\textmu W & 1.118\,mW & \multicolumn{2}{c|}{726\,\textmu W} & 221.1\,\textmu W & 693\,\textmu W & 7.26\,\textmu W \\ \hline
			
			\textbf{Temperature Range} & \multicolumn{8}{c||}{-40\,...\,+85\,°C} & \multicolumn{9}{c|}{-40\,...\,+85\,°C}\\ \hline\hline 
			
			\rowcolor{light grey} $Gyro Specs$ & \multicolumn{17}{c|}{} \\ \hline\hline
			
			\textbf{Measurement Range} & 15.625\,$\frac{\text{deg}}{\text{s}}$ & 31.25\,$\frac{\text{deg}}{\text{s}}$ & 62.5\,$\frac{\text{deg}}{\text{s}}$ & 125\,$\frac{\text{deg}}{\text{s}}$ & 250\,$\frac{\text{deg}}{\text{s}}$ & 500\,$\frac{\text{deg}}{\text{s}}$ & 1000\,$\frac{\text{deg}}{\text{s}}$ & 2000\,$\frac{\text{deg}}{\text{s}}$ & 15.625\,$\frac{\text{deg}}{\text{s}}$ & 31.25\,$\frac{\text{deg}}{\text{s}}$ & 62.5\,$\frac{\text{deg}}{\text{s}}$ & 125\,$\frac{\text{deg}}{\text{s}}$ & 250\,$\frac{\text{deg}}{\text{s}}$ & 500\,$\frac{\text{deg}}{\text{s}}$ & 1000\,$\frac{\text{deg}}{\text{s}}$ & 2000\,$\frac{\text{deg}}{\text{s}}$ & 4000\,$\frac{\text{deg}}{\text{s}}$ \\ \hline
			
			\textbf{Sensitivity} & 2089.2\,$\frac{\text{LSB}}{\frac{\text{deg}}{\text{s}}}$ & 1048.6\,$\frac{\text{LSB}}{\frac{\text{deg}}{\text{s}}}$ & 524.3\,$\frac{\text{LSB}}{\frac{\text{deg}}{\text{s}}}$ & 262\,$\frac{\text{LSB}}{\frac{\text{deg}}{\text{s}}}$ & 131\,$\frac{\text{LSB}}{\frac{\text{deg}}{\text{s}}}$ & 65.5\,$\frac{\text{LSB}}{\frac{\text{deg}}{\text{s}}}$ & 32.8\,$\frac{\text{LSB}}{\frac{\text{deg}}{\text{s}}}$ & 16.4\,$\frac{\text{LSB}}{\frac{\text{deg}}{\text{s}}}$ & 2089.2\,$\frac{\text{LSB}}{\frac{\text{deg}}{\text{s}}}$ & 1048.6\,$\frac{\text{LSB}}{\frac{\text{deg}}{\text{s}}}$ & 524.3\,$\frac{\text{LSB}}{\frac{\text{deg}}{\text{s}}}$ & 262\,$\frac{\text{LSB}}{\frac{\text{deg}}{\text{s}}}$ & 131\,$\frac{\text{LSB}}{\frac{\text{deg}}{\text{s}}}$ & 65.5\,$\frac{\text{LSB}}{\frac{\text{deg}}{\text{s}}}$ & 32.8\,$\frac{\text{LSB}}{\frac{\text{deg}}{\text{s}}}$ & 16.4\,$\frac{\text{LSB}}{\frac{\text{deg}}{\text{s}}}$ & 8.2\,$\frac{\text{LSB}}{\frac{\text{deg}}{\text{s}}}$ \\ \hline
			
			\shortstack[r]{\textbf{Sensitivity Change} \\ \textbf{Due to temperature}} & \multicolumn{8}{c||}{$\pm0.005\,\frac{\%}{°\text{C}}$} & \multicolumn{9}{c|}{$\pm0.01\,\frac{\%}{°\text{C}}$} \\ \hline
			
			\textbf{Zero-rate Offset} & \multicolumn{8}{c||}{$\pm0.5\frac{\text{deg}}{\text{s}}$} & \multicolumn{9}{c|}{$\pm0.3\frac{\text{deg}}{\text{s}}$} \\ \hline
			
			\textbf{Noise} & \multicolumn{8}{c||}{$0.028\frac{\text{deg}}{\text{s}}$-rms} & \multicolumn{9}{c|}{$\pm0.038\frac{\text{deg}}{\text{s}}$-rms} \\ \hline
		\end{tabular}
	\end{adjustbox}
\end{sidewaystable}

\begin{sidewaystable}
	\captionof{table}{Accelerometer characteristics}	
	\label{tab:sensor_acc}
	\begin{adjustbox}{width=1.05\textwidth}
		\begin{tabular}{|r||c|c|c|c||c|c|c|c||c|c|c|c|} \hline		
				& \multicolumn{4}{c||}{\textbf{ADXL345}} & \multicolumn{4}{c||}{\textbf{ADXL343}} & \multicolumn{4}{c|}{\textbf{KX134}} \\ \hline \hline
				
				\textbf{Measurement Range} & 2\,g\tablefootnote[1]{g referring to gravitational acceleration of 9.81\,$\frac{\text{m}}{\text{s}^2}$} & 4\,g & 8\,g & 16\,g & 2\,g & 4\,g & 8\,g & 16\,g & 8\,g & 16\,g & 32\,g & 64\,g \\ \hline
				
				\textbf{Output Resolution} & 10\,bits & 11\,bits & 12\,bits & 13\,bits & 10\,bits & 11\,bits & 12\,bits & 13\,bits & \multicolumn{4}{c|}{16\,bits} \\ \hline
				
				\textbf{Sensitivity} (Typical) & 256\,$\frac{\text{LSB}}{\text{g}}$ & 128\,$\frac{\text{LSB}}{\text{g}}$& 64\,$\frac{\text{LSB}}{\text{g}}$ & 32\,$\frac{\text{LSB}}{\text{g}}$ & 256\,$\frac{\text{LSB}}{\text{g}}$ & 128\,$\frac{\text{LSB}}{\text{g}}$& 64\,$\frac{\text{LSB}}{\text{g}}$ & 32\,$\frac{\text{LSB}}{\text{g}}$ & 4096\,$\frac{\text{LSB}}{\text{g}}$ & 2048\,$\frac{\text{LSB}}{\text{g}}$ & 1024\,$\frac{\text{LSB}}{\text{g}}$ & 512\,$\frac{\text{LSB}}{\text{g}}$ \\ \hline
				
				\multirowcell{2}{\shortstack[r]{\textbf{Sensitivity change}\\ \textbf{due to temperature}}} & \textbf{x} & \textbf{y} & \multicolumn{2}{c||}{\textbf{z}} & \textbf{x} & \textbf{y} & \multicolumn{2}{c||}{\textbf{z}} & \textbf{x} & \textbf{y} & \multicolumn{2}{c|}{\textbf{z}}  \\ \cline{2-13}
				
				 & \multicolumn{4}{c||}{$\pm0.01\,\frac{\%}{\text{°\text{C}}}$} & \multicolumn{4}{c||}{$\pm0.01\,\frac{\%}{\text{°\text{C}}}$} & \multicolumn{2}{c|}{$\pm0.01\,\frac{\%}{\text{°\text{C}}}$} & \multicolumn{2}{c|}{$\pm0.03\,\frac{\%}{\text{°\text{C}}}$} \\ \hline
				 
				\textbf{0g Offset} & \multicolumn{2}{c|}{$\pm0.15\,\text{g}$} & \multicolumn{2}{c||}{$\pm0.25\,\text{g}$} & \multicolumn{4}{c||}{$\pm0.35\,\text{g}$} & \multicolumn{4}{c|}{$\pm0.025\,\text{g}$} \\ \hline
				
				\textbf{Noise} & \multicolumn{2}{c|}{$\pm0.75\,\text{LBS-rms}$} & \multicolumn{2}{c||}{$\pm1.10\,\text{LBS-rms}$} & \multicolumn{4}{c||}{$\pm1.10\,\text{LBS-rms}$} & \multicolumn{4}{c|}{$\pm0.70\,\text{LBS-rms}$} \\ \hline
					
				\multirowcell{2}{\textbf{Operating Voltage} $V_\text{s}$/$V_\text{DD}$} & \textbf{Min} & \multicolumn{2}{c|}{\textbf{Typical}} & \textbf{Max} & \textbf{Min} & \multicolumn{2}{c|}{\textbf{Typical}} & \textbf{Max} & \textbf{Min} & \multicolumn{2}{c|}{\textbf{Typical}} & \textbf{Max} \\ \cline{2-13}
				
				& 2.0\,V & \multicolumn{2}{c|}{2.5\,V} & 3.6\,V & 2.0\,V & \multicolumn{2}{c|}{2.5\,V} & 3.6\,V & 1.7\,V & \multicolumn{2}{c|}{2.5\,V} & 3.6\,V \\ \hline
				
				\textbf{Interface Voltage} $V_\textbf{DDIO}$ & 1.7\,V & \multicolumn{2}{c|}{1.8\,V} & $V_\text{DD}$ & 1.7\,V & \multicolumn{2}{c|}{1.8\,V} & $V_\text{DD}$ & 1.2\,V & \multicolumn{2}{c|}{-} & 3.6\,V \\ \hline
				
				\multirowcell{2}{\textbf{Output Data Rate} (ODR)} & \multicolumn{2}{c|}{\textbf{Min}}& \multicolumn{2}{c||}{\textbf{Max}} & \multicolumn{2}{c|}{\textbf{Min}}& \multicolumn{2}{c||}{\textbf{Max}} & \textbf{Min} & \multicolumn{2}{c|}{\textbf{Typical}} & \textbf{Max} \\ \cline{2-13}
				
				& \multicolumn{2}{c|}{0.1\,Hz} & \multicolumn{2}{c||}{3200\,Hz} & \multicolumn{2}{c|}{0.1\,Hz} & \multicolumn{2}{c||}{3200\,Hz} & 0.781\,Hz & \multicolumn{2}{c|}{50\,Hz} & 25600\,Hz \\ \hline
							
				\multirowcell{2}{\textbf{Current Consumption}} & \multicolumn{2}{c|}{\textbf{ODR$\geq$100\,Hz}} & \textbf{ODR$<$10\,Hz} & \textbf{Standby} & \multicolumn{2}{c|}{\textbf{ODR$\geq$100\,Hz}} & \textbf{ODR$<$10\,Hz} & \textbf{Standby} & \multicolumn{2}{c|}{\textbf{Performance}} & \textbf{Low Power} & \textbf{Standby}  \\ \cline{2-13}
				
				& \multicolumn{2}{c|}{100\,\textmu A} & 30\,\textmu A & 0.1\,\textmu & \multicolumn{2}{c|}{100\,\textmu A} & 30\,\textmu A & 0.1\,\textmu A & \multicolumn{2}{c|}{148\,\textmu A} & 0.53\,\textmu A & 0.5\,\textmu A \\ \hline
				
				\multirowcell{2}{\textbf{Power Consumption}} & \textbf{Min} & \multicolumn{2}{c|}{\textbf{Typical}} & \textbf{Max} & \textbf{Min} & \multicolumn{2}{c|}{\textbf{Typical}} & \textbf{Max} & \multicolumn{4}{c|}{\textbf{For $V_\text{DD}=3.3$\,V}} \\ \cline{2-13}
				
				& 0.28\,mW & \multicolumn{2}{c|}{0.35\,mW} & 0.5\,mW & 0.28\,mW & \multicolumn{2}{c|}{0.35\,mW} & 0.5\,mW & \multicolumn{2}{c|}{$\approx$0.49\,mW} & 1.79\,\textmu W & 1.65\,\textmu W \\ \hline
				
				\textbf{Temperature Range} & \multicolumn{4}{c||}{-40\,...\,+85\,°C} & \multicolumn{4}{c||}{-40\,...\,+85\,°C} & \multicolumn{4}{c|}{-40\,...\,+105\,°C}\\ \hline
				
				\textbf{Weight} & \multicolumn{4}{c||}{30\,mg} & \multicolumn{4}{c||}{30\,mg} & \multicolumn{4}{c|}{-}\\ \hline
		\end{tabular}
	\end{adjustbox}
\end{sidewaystable}

\begin{sidewaystable}
	\captionof{table}{Pressure sensor characteristics}\footnote{psi values are rounded to a precision of one tenth}	
	\label{tab:sensor_pss}
	\begin{adjustbox}{width=1.05\textwidth}
		\begin{tabular}{|r||c|c|c||c|c|c||c|c|c||c|c|c|} \hline		
			& \multicolumn{3}{c||}{\textbf{HSCMAND015PASA5}} & \multicolumn{3}{c||}{\textbf{MS561101BA03-50}} & \multicolumn{3}{c|}{\textbf{MPL3115A2ST1}\footnote[1]{Features an altimeter mode}} & \multicolumn{3}{c|}{\textbf{MS560702BA03-50}} \\ \hline \hline
			
			\rowcolor{light grey} $Pressure sensor Specs$ & \multicolumn{12}{c|}{} \\ \hline \hline
			
			\textbf{Measurement Range} & $1.6\,\textbf{mbara} - 1.0\,\textbf{bara}$ & $160\,\textbf{Pa} - 1\,\textbf{MPa}$ & $0.5\,\textbf{psi} - 14.5\,\textbf{psi}$
			& $450\,\textbf{mbara} - 1.1\,\textbf{bara}$ & $45\,\textbf{kPa} - 110\,\textbf{kPa}$\footnote[2]{Extended usable range of 1\,kPa - 120\,kPa. The ADC shows linear behaviour in the above mentioned range, but can be extended to this range with custom calibrations.} & $6.5\,\textbf{psi} - 16.0\,\textbf{psi}$
			& $500\,\textbf{mbara} - 1.1\,\textbf{bara}$ & $50\,\textbf{kPa} - 110\,\textbf{kPa}$\footnote[3]{Extended usable range of 20\,kPa - 120\,kPa with similar ADC behaviour to the MS561101BA03-50} & $7.3\,\textbf{psi} - 16.0\,\textbf{psi}$
			& $300\,\textbf{mbara} - 1,1\,\textbf{bara}$ & $30\,\textbf{Pa} - 110\,\textbf{kPa}$\footnote[4]{Extended usable range of 1\,kPa - 200\,kPa with similar ADC behaviour to the MS561101BA03-50} & $4.4\,\textbf{psi} - 16.0\,\textbf{psi}$ \\ \hline
			
			\textbf{Pressure Accuracy} & \multicolumn{3}{c||}{$\pm0.25\,\%$} & \multicolumn{3}{c||}{$\pm0.25\,$kPa} & \multicolumn{3}{c||}{$\pm0.4\,$kPa} & \multicolumn{3}{c|}{$\pm0.15\,$kPa} \\ \hline
			
			\textbf{Output Resolution} & \multicolumn{3}{c||}{12\,bits} & \multicolumn{3}{c||}{8 - 12\,bits} & \multicolumn{3}{c||}{20\,bits} & \multicolumn{3}{c|}{8 - 12\,bits} \\ \hline
			
			\textbf{Long term stability} & \multicolumn{3}{c||}{N/A} & \multicolumn{3}{c||}{$\pm0.1\,\frac{\text{kPa}}{\text{yr}}$} & \multicolumn{3}{c||}{$\pm0.1\,\frac{\text{kPa}}{\text{yr}}$} & \multicolumn{3}{c|}{$\pm0.1\,\frac{\text{kPa}}{\text{yr}}$} \\ \hline
			
			\textbf{Max Pressure}\footnote[4]{Referring to the most pressure it can sustain without breaking} & \multicolumn{3}{c||}{N/A} & 6\,bar & 600\,kPa & 87.0\,psi & 5\,bar & 500\,kPa & 72.5\,kPa & 6\,bar & 600\,kPa & 87.0\,psi \\ \hline
			
			\textbf{Noise} & \multicolumn{3}{c||}{N/A} & \multicolumn{2}{c|}{1.2 (4096), 1.8 (2048), 2.7 (1024), 4.2 (512), 6.5 (256)} & Pa-rms (OSR) & \multicolumn{2}{c|}{19 (1) 1.5 (128)} & Pa-rms (OSR) & \multicolumn{2}{c|}{2.4 (4096), 3.6 (2048), 5.4 (1024), 8.4 (512), 13.0 (256)} & Pa-rms (OSR) \\ \hline
			
			\multirowcell{2}{\textbf{Operating Voltage} $V_\text{s}$/$V_\text{DD}$} & \textbf{Min} & \textbf{Typical} & \textbf{Max} & \textbf{Min} & \textbf{Typical} & \textbf{Max} & \textbf{Min} & \textbf{Typical} & \textbf{Max} & \textbf{Min} & \textbf{Typical} & \textbf{Max} \\ \cline{2-13}
			
			& 3.0\,V & 3,3\,V & 3.6\,V & 1.8\,V & 3.0\,V & 3.6\,V & 1.95\,V & 2.5\,V & 3.6\,V & 1.8\,V & 3.0\,V & 3.6\,V \\ \hline
			
			\textbf{Interface Voltage} $V_\textbf{DDIO}$ & \multicolumn{3}{c||}{N/A} & \multicolumn{3}{c||}{N/A} & 1.62\,V & 1.8\,V & 3.6\,V & \multicolumn{3}{c|}{N/A} \\ \hline
			
			\multirowcell{2}{\textbf{Output Data Rate} (ODR)} & \textbf{SPI} (Max) & \multicolumn{2}{c||}{\textbf{I2C} (Max)} & \textbf{SPI} (Max) & \multicolumn{2}{c||}{\textbf{I2C} (Max)} & \textbf{I2C $f_\text{SCL}1$} (with $C_\text{Bus} = 20\,$pF)& \multicolumn{2}{c||}{\textbf{I2C $f_\text{SCL}2$} (with $C_\text{Bus} = 400\,$pF)} & \textbf{SPI} (Max) & \multicolumn{2}{c|}{\textbf{I2C} (Max)} \\ \cline{2-13}
			
			& 800\,kHz & \multicolumn{2}{c||}{400\,kHz} & 20\,MHz & \multicolumn{2}{c||}{400\,kHz} & 400\,kHz & \multicolumn{2}{c||}{4\,MHz} & 20\,MHz & \multicolumn{2}{c|}{400\,kHz}  \\ \hline
			
			\multirowcell{2}{\textbf{Current Consumption}} & \textbf{Supply} (typical) & \multicolumn{2}{c||}{\textbf{Supply} (max)} & \textbf{Supply} & \textbf{Peak} & \textbf{Standby} & \textbf{Operational} & \textbf{Peak} & \textbf{Standby} & \textbf{Supply} & \textbf{Peak} & \textbf{Standby}  \\ \cline{2-13}
			
			& 3.1\,mA & \multicolumn{2}{c||}{3.9\,mA} & 12.5\,\textmu A (4096)\footnote[5]{Maximum operational supply. The Consumption is dependent on OSR.\label{note:current_OSR}} & 1.4\,mA & 0.14\,\textmu A & 265\,\textmu A\footref{note:current_OSR} & 2\,mA & 2\,\textmu A & 12.5\,\textmu A\footref{note:current_OSR} & 1.4\,mA & 0.14\,\textmu A \\ \hline
			
			\multirowcell{2}{\textbf{Power Consumption}} & \multicolumn{3}{c||}{\textbf{For $V_\text{DD} = 3.3\,$V}} & \multicolumn{3}{c||}{\textbf{For $V_\text{DD} = 3.3\,$V}} & \multicolumn{3}{c||}{\textbf{For $V_\text{DD} = 3.3\,$V}} & \multicolumn{3}{c|}{\textbf{For $V_\text{DD} = 3.3\,$V}} \\ \cline{2-13}
			
			& 10.23\,mW & \multicolumn{2}{c||}{12.87\,mW} & 42.24\,\textmu W & 4.62\,mW & 0.462\,\textmu W & 844.8\,\textmu W & 6.6\,mW & 6.6\,\textmu W & 41.25\,\textmu W & 4.62\,mW & 0.462\,\textmu W\\ \hline
			
			\textbf{Temperature Range} & \multicolumn{3}{c||}{-20\,...\,+85\,°C} & \multicolumn{3}{c||}{-40\,...\,+85\,°C} & \multicolumn{3}{c||}{-40\,...\,+85\,°C} & \multicolumn{3}{c|}{-40\,...\,+85\,°C}\\ \hline \hline
			
			\rowcolor{light grey} $Temperature sensor Specs$ & \multicolumn{12}{c|}{} \\ \hline \hline
			
			\textbf{Measurement Range} & \multicolumn{3}{c||}{} & \multicolumn{3}{c||}{-40\,...\,+85\,°C} & \multicolumn{3}{c||}{-40\,...\,+85\,°C} & \multicolumn{3}{c|}{-40\,...\,+85\,°C} \\ \cline{5-13}
			
			\multirowcell{2}{\textbf{Accuracy}} & \multicolumn{3}{c||}{} & \textbf{Min} & \textbf{-20\,...\,+85\,°C} & \textbf{Max} & \multicolumn{3}{c||}{Max Offset} & \textbf{Min} & \textbf{-20\,...\,+85\,°C} & \textbf{Max} \\ \cline{5-13}
			
			& \multicolumn{3}{c||}{} & -0.8\,°C & $\pm$2.0\,°C & +0.8\,°C & \multicolumn{3}{c||}{$\pm$3\,°C} & -0.8\,°C & $\pm$2.0\,°C & +0.8\,°C \\ \cline{5-13}
			
			\textbf{Resolution} & \multicolumn{3}{c||}{} & \multicolumn{3}{c||}{24\,bits} & \multicolumn{3}{c||}{12\,bits} & \multicolumn{3}{c|}{24\,bits} \\ \cline{5-13}
			
			\textbf{Noise} & \multicolumn{3}{c||}{} & \multicolumn{2}{c|}{0.002 (4096), 0.003 (2048), 0.005 (1024), 0.008 (512), 0.012 (256)} & °C (OSR) & \multicolumn{3}{c||}{N/A} & \multicolumn{2}{c|}{0.002 (4096), 0.003 (2048), 0.005 (1024), 0.008 (512), 0.012 (256)} & °C (OSR) \\ \hline			
		\end{tabular}
	\end{adjustbox}
\end{sidewaystable}

\end{document}

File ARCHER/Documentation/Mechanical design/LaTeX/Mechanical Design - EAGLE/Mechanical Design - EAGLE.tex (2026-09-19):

\documentclass[fontsize=11pt,%
twoside,% oneside als Alternative m\"{o}glich
BCOR          = 8mm, % bei Bedarf anzupassen
DIV           = 11,  % kann nach Belieben geändert werden
titlepage     = off,%
index=totoc,%
xcolor        = pdftex,%
dvipsnames,%
bibliography  = totoc,%
bibliography = numbered, % bei Bedarf einschalten
listof        = notnumbered]{scrreprt}

\usepackage[left=3.5cm,right=2cm,top=2.5cm,bottom=2cm]{geometry}
\usepackage[english]{babel}                         %deutsches Sprachpacket
\usepackage[utf8]{inputenc}                         %input utf8
\usepackage[official]{eurosym}                      %Symbolsatz
\usepackage{amsmath}                                %Mathepacket
\usepackage{siunitx}                                %Package für zwei nachfolgende Befehle
\sisetup{locale=UK}
\sisetup{per-mode=fraction}
\usepackage{graphicx}                               %Bilder einfügen
\usepackage{subfigure}                              %Subfigures erstellen
\usepackage[onehalfspacing]{setspace}               %für Abstände
\usepackage{booktabs}                               %Für Ruler in Tabellen
\usepackage{makecell}
\usepackage{caption}
\usepackage{tabulary}
\usepackage{adjustbox}
\usepackage{subcaption}
\usepackage{acronym}
\usepackage[stable]{footmisc}
\usepackage[
backend=biber,
style=numeric,
sorting=none
]{biblatex}
\DefineBibliographyStrings{english}{
	bibliography = {References}
}
\addbibresource{mybibFile.bib} %Import the bibliography file
\counterwithin{figure}{section}
\counterwithin{table}{section}
\counterwithin{equation}{section}

\begin{document}

\begin{titlepage}
	\centering

	\begin{center}
	\captionsetup{font=footnotesize}
	\begin{figure}[!h]
		\subfigure{}
        \hspace{0.5cm}
		\subfigure{}
    \end{figure}
    \end{center}

	{\scshape\LARGE Technische Hochschule Mittelhessen \\ und \\ Spacelfight Rocketry Gießen e.V.\par}
	\vspace{1cm}
	{\scshape\Large Projektarbeit\par}
	\vspace{1cm}
	{\huge\bfseries Mechanical Design of Electronic Actuaion \& Guidance for Landing and Elevation (EAGLE) system\par}
	\vspace{0.25cm}
    \rule{\textwidth}{.5pt}
    \vspace{.25cm}
    {\large\bfseries Mechanisches Design des Electronic Acutation \& Guidance for Landing and Elevation (EAGLE) Systems\par}
    \vspace{.3cm}
	{\Large\scshape SoSe 2025/26\par}
	\vspace{1cm}
	{\Large \textbf{vorgelegt von}\\ Jason Gläser\par}
	\vfill
	betreut durch\par
    Prof. Dr. Chris Volkmar
	\vfill

% Bottom of the page
	{\large \today\par}
	\cleardoublepage
\end{titlepage}

\setcounter{page}{1}
\pagenumbering{Roman}

\chapter*{Abstract}
The development of the "Electronic Actuation \& Guidance for Landing and Elevation" (EAGLE) system is a project developed in cooperation with the student rocketry association "Spaceflight Rocketry Gießen e.V." as part of its rocket ARCHER which is meant to compete in the "European Rocketry Challenge'' in October 2026. Therefore, I would like to thank Spaceflight Rocketry Giessen for giving me the opptortunity to pursue this project with their funding.\\
EAGLE is a Hardware-in-the-loop (HIL) application consisting of a printed circuit board (PCB) and a mechanism to actuate flaps to control the maximum altitude of a rocket. The aim of this project is to design a minimal viable product of the mechanical assembly suitable for simulations and test flights and evaluate production costs for future rockets.

\newpage
\tableofcontents
\cleardoublepage

\listoffigures
\cleardoublepage

\listoftables
\cleardoublepage

\chapter*{List of abbreviations}
	\begin{acronym}
		\acro{SRPOG}[SPROG]{\dotfill Spaceflight Rocketry Giessen}
		\acro{eV}[e.V.]{\dotfill eingetragener Verein}
		\acro{EAGLE}[EAGLE]{\dotfill Electronic Acutation \& Guidance for Landing and Eleveation}
		\acro{PIPE}[PIPE]{\dotfill Project for Inital Practical Experimentation}
		\acro{ARCHER}[ARCHER]{\dotfill Aerial Rocket for Competions and High-altitude Experimental Rocketry}
		\acro{GNC}[GNC]{\dotfill Guidance, Navigation and Control}
		\acro{PCB}[PCB]{\dotfill Printed Circuit Board}
		\acro{MVP}[MVP]{\dotfill Minimal viable product}
		\acro{PWM}[PWM]{\dotfill Power Width Modulation}
		\acro{IC}[IC]{\dotfill Integrated circuit}
		\acro{PSU}[PSU]{\dotfill Power supply unit}
		\acro{SMD}[SMD]{\dotfill Surface mounted devices}
		\acro{HIL}[HIL]{\dotfill Hardware-in-the-loop}
		\acro{SPI}[SPI]{\dotfill Serial peripheral interface}
		\acro{I2C}[I2C]{\dotfill Inter-Integrated Circuit}
		\acro{UART}[UART]{\dotfill Universal Asynchronous Receiver-Transmitter}
		\acro{RAM}[RAM]{\dotfill Random access memory}
		\acro{UPDI}[UPDI]{\dotfill Unified Program and Debug Interface}
		\acro{GND}[GND]{\dotfill Ground}
		\acro{ASCENT}[ASCENT]{\dotfill Advanced System for Control Electronics, Navigation and Tracking}
		\acro{EUROC}[EUROC]{\dotfill European Rocketry Challenge}
		\acro{COTS}[COTS]{\dotfill Commercial Off-The-Shelf}
		\acro{IMU}[IMU]{\dotfill Inertial Measurement Unit}
		\acro{JLU}[JLU]{\dotfill Justus-Liebig-University Giessen}
		\acro{THM}[THM]{\dotfill Technische Hochschule Mittelhessen}
		\acro{CG}{\dotfill Center of gravity}
		\acro{CP}{\dotfill Center of pressure}
		\acro{AoA}{\dotfill Angle of attack}
		\acro{DoF}{\dotfill Degree of freedom}
	\end{acronym}
	\cleardoublepage

\setcounter{page}{1}
\pagenumbering{arabic}

\chapter{Introduction}
"Spaceflight Rocketry Gießen e.V." (SPROG) is a student-founded and ran rocketry association at the Justus Liebig University and University of Applied Sciences in Gießen, which develops and builds experimental rockets, with which the association wants to compete at international student rocketry competitions such as the "European Rocketry Challenge" in Portugal.

\section{Note of thanks}
I would like to thank Vincent Uebel - M.Sc. Mechanical Engineering graduate from "Technische Hochschule Mittelhessen" (THM) and member of SPROG - for contributing to the design process and CAD-Design of the airbrake v1 design and conceptualizing ideas in the early stages of the project.

\section{Motivation}
In August 2024, SPROG launched its first ever rocket PIPE in Bremen. Since then, it became SPROG's main objective to particiapte in the "European Rocketry Challenge" (EUROC). To increase chances of being invited to compete at EUROC and to maximise point scoring by accurately reaching a targeted altitude, it was decided to introduce the Electronic Acutation \& Guidance for Landing and Eleveation (EAGLE) system to the rocket "ARCHER''. EAGLE also serves as a platform to learn basic Guidance, Navigation and Control (GNC) workflows, Hardware-in-the-loop (HIL) and concepts such as mathematical simulations, control engineering and aerodynamic analysis, whilst utilizing mechanisms and designs similar to industry practice (i.e. grid fins). \\
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

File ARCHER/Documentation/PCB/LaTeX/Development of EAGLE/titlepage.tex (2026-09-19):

%% Titlepage
%  Note: all text inside < ... > has to be adapted!
{% enclose this page so what is defined here does not spill over elsewhere
\pagestyle{empty}
\setstretch{1.5}
\sffamily
%\hfill\includegraphics{logo_univie_bw}

\centering% the switch form will also prevent hyphenation which would be undesired for a title

\vfill
{\bfseries\Huge PROJEKTARBEIT}

\vfill
Titel der Projektarbeit

{\LARGE\bfseries Development of Electronic Actuatuion \& Guidance for Landing and Elevation (EAGLE) v1.2.1}
\vfill

vorgelegt von

{\Large Jason Gläser}

\vspace{15mm}

\vspace{15mm}

\raggedright
%\small
\centering
\begin{tabular}{p{0.25\textwidth}p{0.75\textwidth}}
Datum:          & \today \\[1.0ex]
Studiengang:    &  PTRA - Physik und Technologie f\"{u}r Raumfahrtanwendungen\\[1.0ex]
Matrikelnummer: &  5444564\\[1.0ex]
Erstgutachter:  &  Prof. Dr. Daniel D\"{u}sentrieb \\[1.0ex]
\end{tabular}
\cleardoublepage
% \end{titlepage}
}%end of title page

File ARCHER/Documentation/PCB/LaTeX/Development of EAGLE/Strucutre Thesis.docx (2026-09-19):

# Revised Structure

1. Introduction

- Motivation: role of recovery systems in sounding rockets, why reliable actuation of airbrakes and parachute deployment matters
- Problem statement: designing a recovery module PCB compliant with EuRoC rules
- Objectives and scope (explicit about untested status)
- Thesis outline

2. Background and Related Work
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

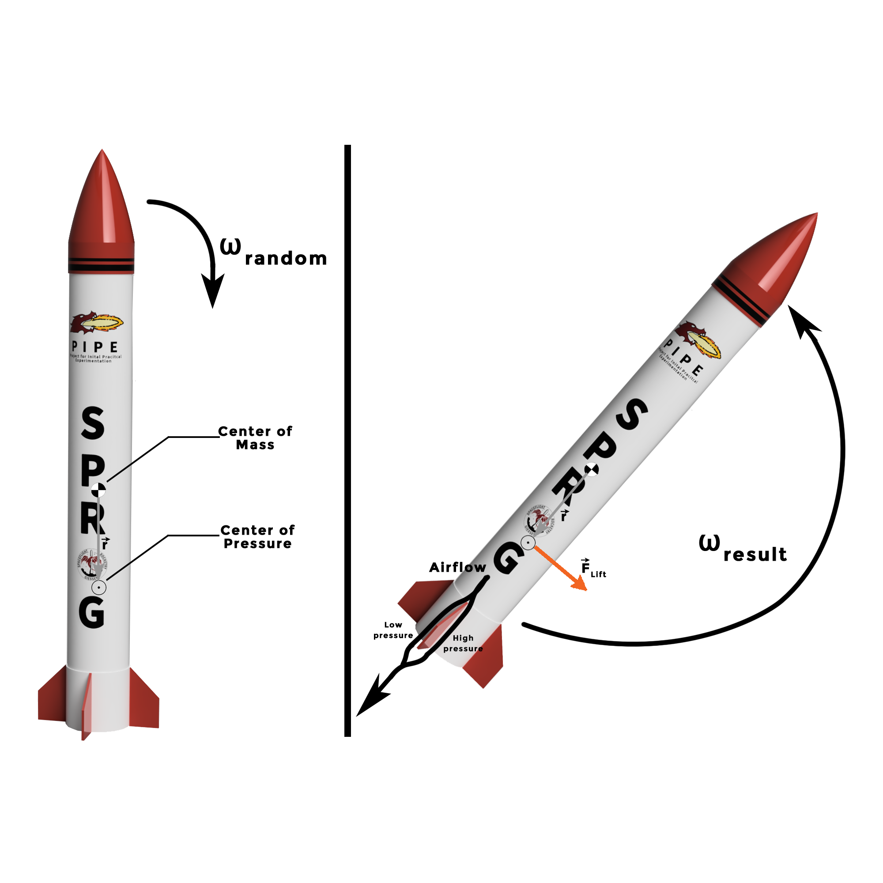
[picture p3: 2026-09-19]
ARCHER/Documentation/Mechanical design/LaTeX/Mechanical Design - EAGLE/Stability 2.png

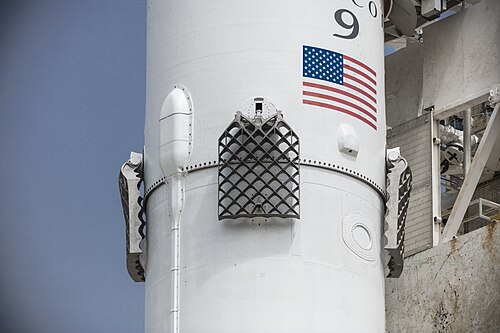
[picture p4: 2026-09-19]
ARCHER/Documentation/Mechanical design/LaTeX/Mechanical Design - EAGLE/SpaceX grid fins.jpg

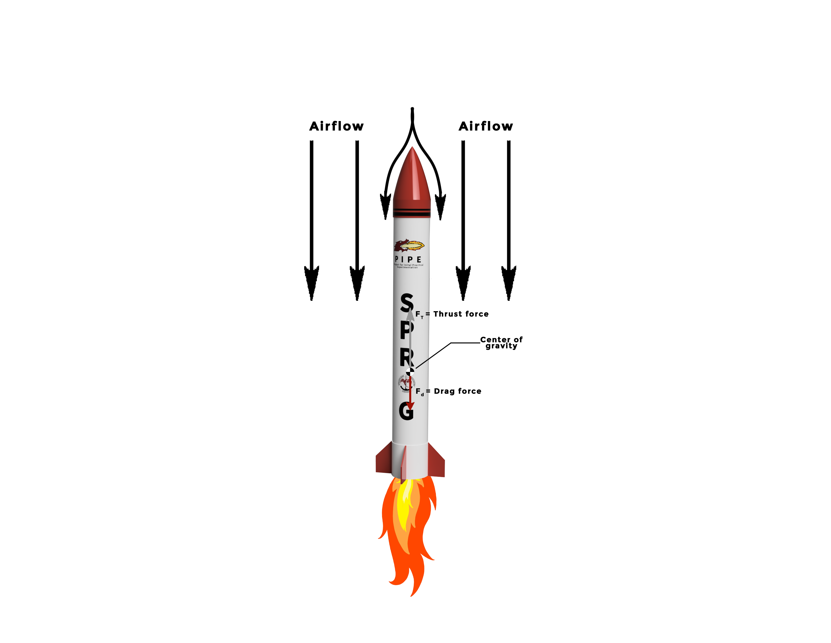
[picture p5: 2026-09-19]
ARCHER/Documentation/Mechanical design/LaTeX/Mechanical Design - EAGLE/Aerodynamcal drag.png

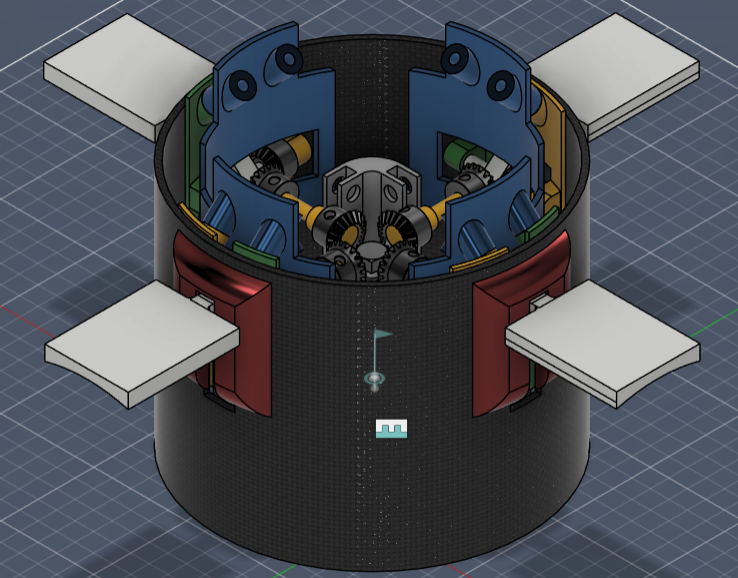
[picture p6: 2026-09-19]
ARCHER/Documentation/Mechanical design/LaTeX/Mechanical Design - EAGLE/Airbrakes v2 - open.png

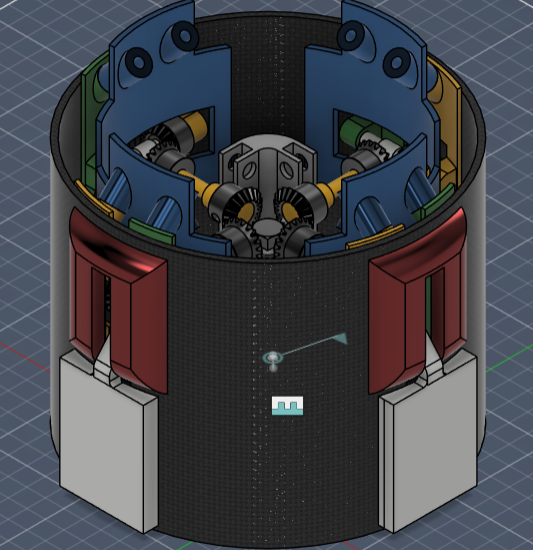
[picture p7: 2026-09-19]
ARCHER/Documentation/Mechanical design/LaTeX/Mechanical Design - EAGLE/Airbrakes v2 - closed.png

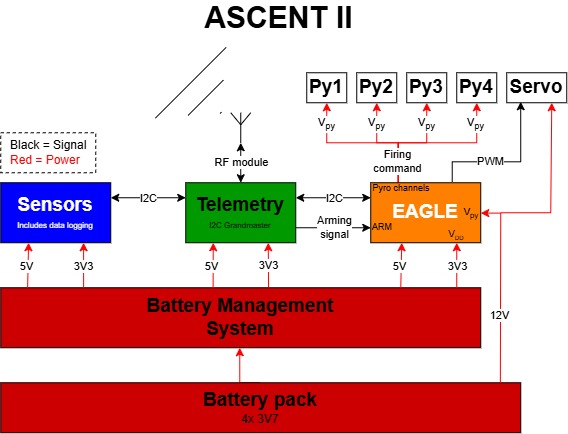
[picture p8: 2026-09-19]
ARCHER/Documentation/PCB/LaTeX/Development of EAGLE/ASCENT II Architecture.jpg

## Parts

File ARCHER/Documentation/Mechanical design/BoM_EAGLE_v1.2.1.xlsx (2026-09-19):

Reference | Value | Footprint | Datasheet | Qty | DNP | Exclude from BOM | Exclude from Board
ADXL375 | ~ | Footprint Library v1.1.0:SPROG_ADXL375-M |  | 1
C1,C2,C3,C4,C5,C7,C9 | 100 nF | Capacitor_SMD:C_0805_2012Metric | ~ | 7
C6 | 2.2 uF | Capacitor_SMD:C_0805_2012Metric | ~ | 1
C8,C12,C14,C16 | 10 uF | Capacitor_SMD:C_0805_2012Metric | ~ | 4
C10,C11 | 0.1 uF | Capacitor_SMD:C_0805_2012Metric | ~ | 2
C13,C15 | 1 uF | Capacitor_SMD:C_0805_2012Metric | ~ | 2
CP2102N-A02-GQFN28 | CP2102N-A02-GQFN28 | Footprint Library v1.1.0:SPROG_CP2102N-A02-GQFN28 |  | 1
D1 | Debug | Diode_SMD:D_0805_2012Metric | ~ | 1
D2 | LED | LED_SMD:LED_0805_2012Metric | ~ | 1
D3 | 1N5819HW-7-F | Footprint Library v1.1.0:SPROG_1N5819HW-7-F |  | 1
D4,D5,D6,D7 | D_Zener_Small | Footprint Library v1.1.0:SPROG_AQ4020_LTF | ~ | 4
D8,D9,D10,D11,D12,D13,D14,D15 | Shottkey | Footprint Library v1.1.0:SPROG_DO214AA_MBRS_VIS | ~ | 8
ESP32-S3-WROOM-1U-N4 | ESP32-S3-WROOM-1U-N4 | Footprint Library v1.1.0:SPROG_ESP32-S3-WROOM-1U-N4 |  | 1
ICM-42688-P1 | ICM-42688-P | Footprint Library v1.1.0:SPROG_ICM-42688-P |  | 1
J1 | RTS (EN) | Connector_PinHeader_2.54mm:PinHeader_1x01_P2.54mm_Vertical | ~ | 1
J2 | 6130XX21121_61300621121 | Footprint Library v1.1.0:SPROG_61300621121 |  | 1
J3 | GSB1C411101DS1HR | Footprint Library v1.1.0:SPROG_GSB1C411101DS1HR |  | 1
J4 | Screw_Terminal_01x04 | Footprint Library v1.1.0:SPROG_CONN4_S04B-PASK_JST | ~ | 1
J5 | TBLH10-350-10BK | Footprint Library v1.1.0:SPROG_TBLH10-350-10BK |  | 1
J6 | TTL | Connector_PinSocket_2.54mm:PinSocket_1x06_P2.54mm_Horizontal | ~ | 1
KX134 | ~ | Footprint Library v1.1.0:SPROG_KX134-1211 |  | 1
MCP23017T-E_SO1 | MCP23017T-E_SO | Footprint Library v1.1.0:SPROG_MCP23017T-E_SO |  | 1
MPL3115A2ST1 | ~ | Footprint Library v1.1.0:SPROG_MPL3115A2 |  | 1
MS561101BA03-1 | ~ | Footprint Library v1.1.0:SPROG_MS561101BA03-50 |  | 1
Q1,Q2,Q3,Q4,Q5,Q6,Q7,Q8,Q9 | PMV37ENEAR | Footprint Library v1.1.0:SPROG_SOT23_PMV37_NEX | PMV37ENEAR | 9
Q10,Q11 | NPN | Package_SO:Zetex_SM8 | https://ngspice.sourceforge.io/docs/ngspice-html-manual/manual.xhtml#cha_BJTs | 2
R1,R2,R3,R4,R6,R7,R34,R35,R36,R48,R49 | 10k | Resistor_SMD:R_0805_2012Metric | ~ | 11
R5,R24 | 56R | Resistor_SMD:R_0805_2012Metric | ~ | 2
R8,R9,R10,R11,R12,R13,R14,R15,R16,R17,R18,R21,R22,R23,R27,R28,R29,R30,R46,R47,R50,R51 | 0R | Resistor_SMD:R_0805_2012Metric | ~ | 22
R19,R20,R31 | 5R1 | Resistor_SMD:R_0805_2012Metric | ~ | 3
R25 | 50R | Resistor_SMD:R_0805_2012Metric | ~ | 1
R26 | OR | Resistor_SMD:R_0805_2012Metric | ~ | 1
R32 | 22k1 | Resistor_SMD:R_0805_2012Metric | ~ | 1
R33 | 47k5 | Resistor_SMD:R_0805_2012Metric | ~ | 1
R37 | 1k | Resistor_SMD:R_0805_2012Metric | ~ | 1
R38,R39,R43 | 1R5 | Footprint Library v1.1.0:SPROG_RES_PWR263S-20-1R50J | ~ | 3
R40,R42,R44,R45 | 300k | Resistor_SMD:R_0805_2012Metric | ~ | 4
R41 | 5R1 | Footprint Library v1.1.0:SPROG_RES_PWR263S-20-1R50J | ~ | 1
SN74AHC14BQAR1 | SN74AHC14BQAR | Footprint Library v1.1.0:SPROG_SN74AHC14BQAR | https://www.ti.com/lit/ds/symlink/sn74ahc14.pdf?ts=1728545676015 | 1
SW1 | EN | Footprint Library v1.1.0:SPROG_SW_PTS810_SJM | ~ | 1
SW2 | IO0 | Footprint Library v1.1.0:SPROG_SW_CHS-01TA_NDC | ~ | 1
SW3 | Prog. | Footprint Library v1.1.0:SPROG_SW_PTS810_SJM | ~ | 1

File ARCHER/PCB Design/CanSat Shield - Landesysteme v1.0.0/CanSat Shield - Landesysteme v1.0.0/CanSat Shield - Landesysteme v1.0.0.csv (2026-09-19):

ID | Bezeichner | Footprint | Stückzahl | Bezeichnung | Anbieter und Referenz
1 | MPU6500 | QFN24_3X3X0P9_IVS-M | 1 | ~
2 | IO39,IO38,IO46,IO47,IO37,IO36,IO41,IO42,IO48,IO35,IO40,IO45 | SolderWire-0.1sqmm_1x01_D0.4mm_OD1mm | 12 | Conn_01x01
3 | J6,J5 | PinSocket_1x02_P2.54mm_Vertical | 2 | Conn_01x02_Socket
4 | R24,R26,R25,R25,R23,R23,R25,R24 | R_0805_2012Metric | 8 | 56R
5 | D4,D2,D3,D1 | LED_0805_2012Metric | 4 | 2V
6 | R18,R12,R9,R20,R11,R17,R13,R16,R8,R10,R21,R7,R14,R15,R19,R22 | R_0805_2012Metric | 16 | 0R
7 | Connector | CONN_SM06B-GHS-TB_JST | 1 | Connector
8 | R5,R2,R1,R6,R4,R3 | R_0805_2012Metric | 6 | 10k
9 | C14,C13,C4,C1,C2 | C_0805_2012Metric | 5 | 100 nF
10 | SCLK | MISO | MOSI | SDA1 | SDA0 | SCL0 | SCL1 | TX2 | RX2 | TX1 | RX1 | CS | GND | 3V3 | TerminalBlock_Xinya_XY308-2.54-14P_1x14_P2.54mm_Horizontal | 1 | Screw_Terminal_01x14
11 | REF** | PinHeader_1x01_P1.00mm_Vertical | 1 | PinHeader_1x01_P1.00mm_Vertical
12 | MS561101BA03-1 | XDCR_MS561101BA03-50 | 1 | ~
13 | MPL3115A2ST1 | PSON80P300X300X100-8N | 1 | ~
14 | C3 | C_0805_2012Metric | 1 | 10 uF
15 | C5 | C_0805_2012Metric | 1 | 10 nF
16 | C6 | C_0805_2012Metric | 1 | 0,1 uF
17 | HIGH,SW2,ADXL,HIGH | SW_JS202011JCQN | 4 | JS202011JAQN (Switch)
18 | SW1(Slideswitch)1 | SW_CHS-01TA_NDC | 1 | GND if disengaged, IO0 if engaged
19 | KX1 | XDCR_KX003-1077 | 1 | ~
20 | C7,C8,C9,C11 | C_0805_2012Metric | 4 | 0.1 uF
21 | ESP32 S3 Wroom 1u | XCVR_ESP32-S3-WROOM-1U | 1 | ESP32-S3-WROOM-1U
22 | Boot | SW_SPST_PTS810 | 1 | ~
23 | J1 | PinSocket_1x06_P2.54mm_Horizontal | 1 | TTL
24 | ADXL1 | LGA_CC-14-1_ADI-M | 1 | ~
25 | C10 | C_0805_2012Metric | 1 | 1 uF
26 | J4 | PinSocket_1x09_P2.54mm_Vertical | 1 | Tele-GND
27 | EN | SW_SPST_PTS810 | 1 | Works as reset button

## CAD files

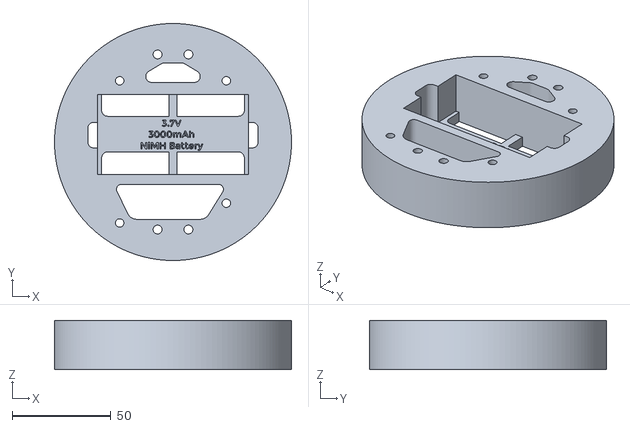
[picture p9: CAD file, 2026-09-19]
ARCHER/CAD Design/Batteriehalterung v11.stl
120.0 x 120.0 x 25.0

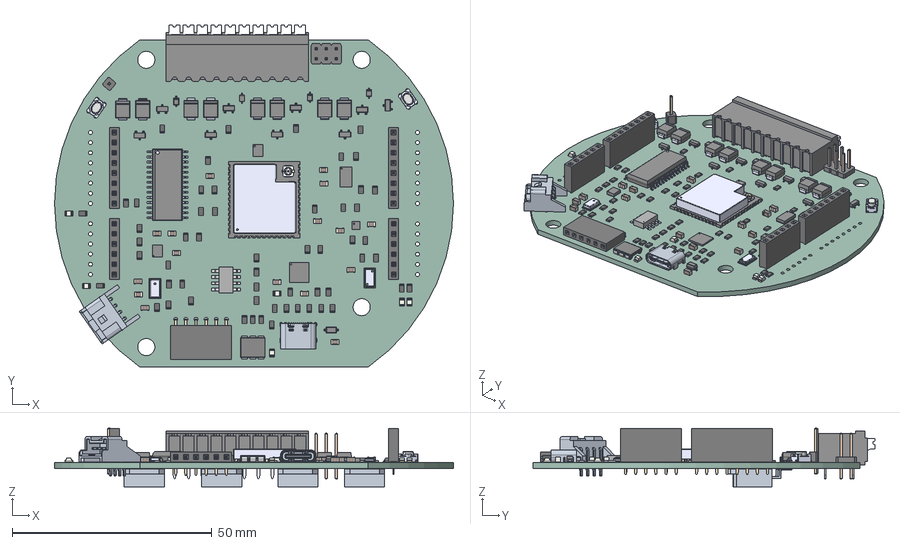
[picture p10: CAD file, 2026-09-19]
ARCHER/Misc/EAGLE_Recovery_v1.2.1.step
100.0 x 85.7 x 14.7 mm
SSB44-E3_52T x 8
PinHeader_1x01_P2.54mm_Vertical
PMV37ENEAR x 9
R_0805_2012Metric x 56
PinSocket_1x08_P2.54mm_Vertical x 2
PinSocket_1x06_P2.54mm_Vertical x 2
C_0805_2012Metric x 16
MS561101BA03-50
PTS810_SJM_250_SMTR_LFS x 2
LED_0805_2012Metric x 6
PLCC6_CLP6C-FKB_CRW
1N5819HW-7-F
ESP32-S3-WROOM-1U-N4
ICM-42688-P
SN74AHC14BQAR
AQ4020-01FTG-C x 4
MPL3115A2
PinSocket_1x06_P2.54mm_Horizontal
KX134-1211
TBLH10-350-10BK
MCP23017T-E_SO
ADXL375BCCZ-RL7
EAGLE_Recovery_v1.2.1 1.115
CP2102N-A02-GQFN28
6130xx21121_PIN x 6
SM8_ZDT1048_3P5X6P5_DIO
GSB1C411101DS1HR
PWR263S-20-1R50J x 4
EAGLE_Recovery_v1.0.0_PCB

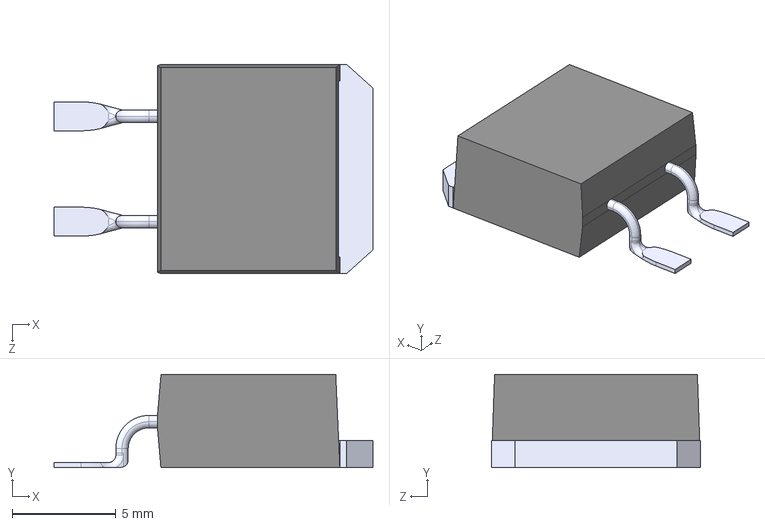
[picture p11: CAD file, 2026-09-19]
ARCHER/PCB Design/KiCAD 3D-Models/PWR263S-35-1R50J.step
15.4 x 4.50 x 10.1 mm

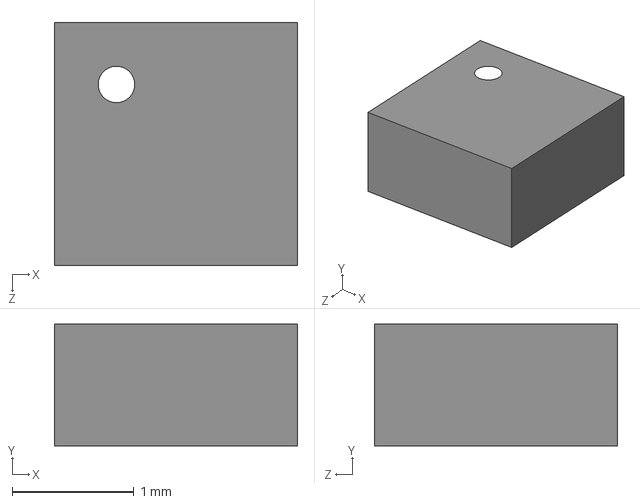
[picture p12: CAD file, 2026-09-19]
ARCHER/PCB Design/KiCAD 3D-Models/KX134-1211.step
2.00 x 1.00 x 2.00 mm

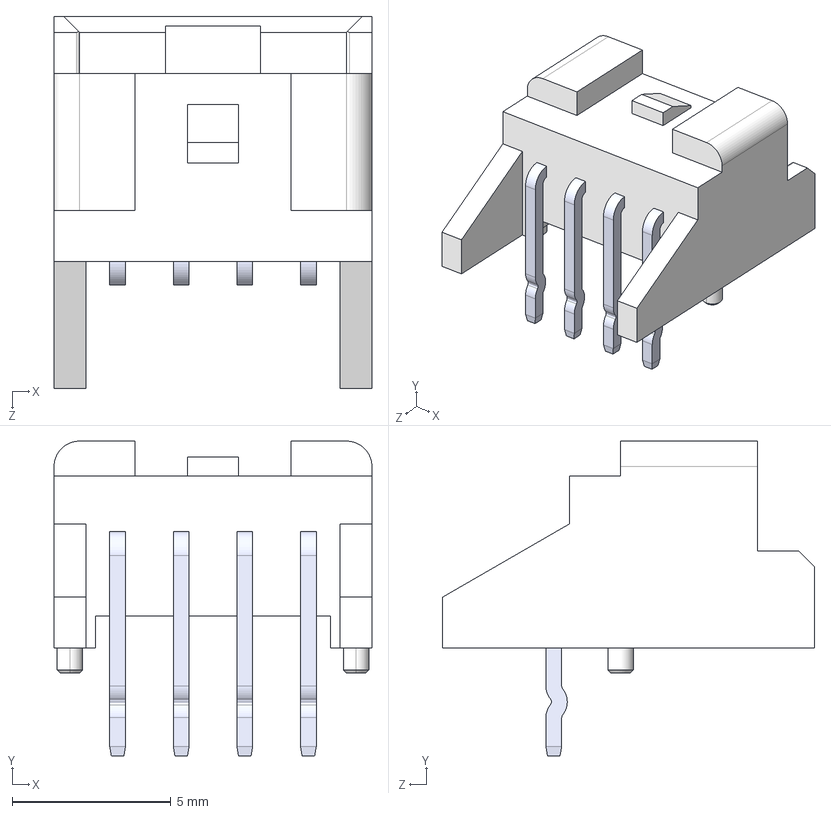
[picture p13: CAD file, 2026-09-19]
ARCHER/PCB Design/KiCAD 3D-Models/S04B-PASK-2.STEP
10.0 x 9.90 x 11.7 mm

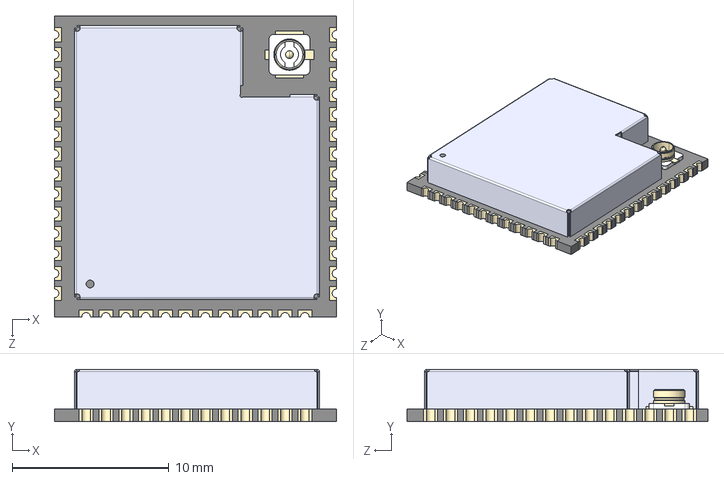
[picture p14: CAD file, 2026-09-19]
ARCHER/PCB Design/KiCAD 3D-Models/ESP32-S3-WROOM-1U-N4.step
18.0 x 3.35 x 19.2 mm

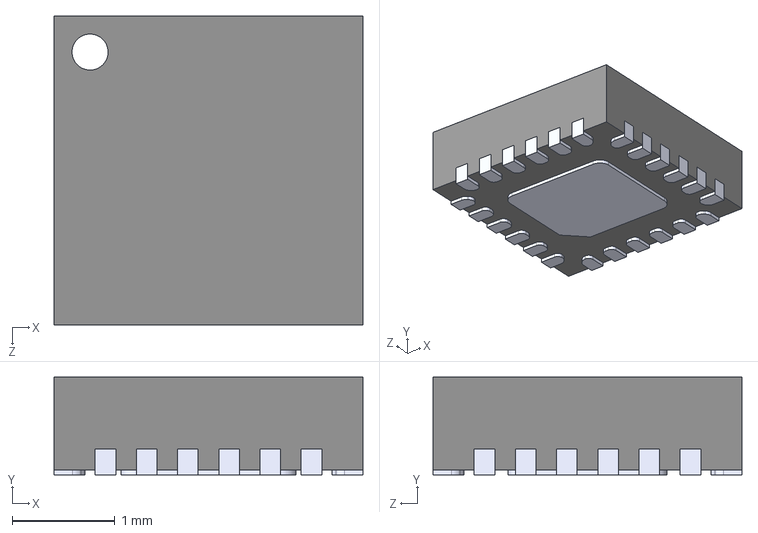
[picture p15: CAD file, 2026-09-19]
ARCHER/PCB Design/KiCAD 3D-Models/MPU-6500.step
3.00 x 0.95 x 3.00 mm

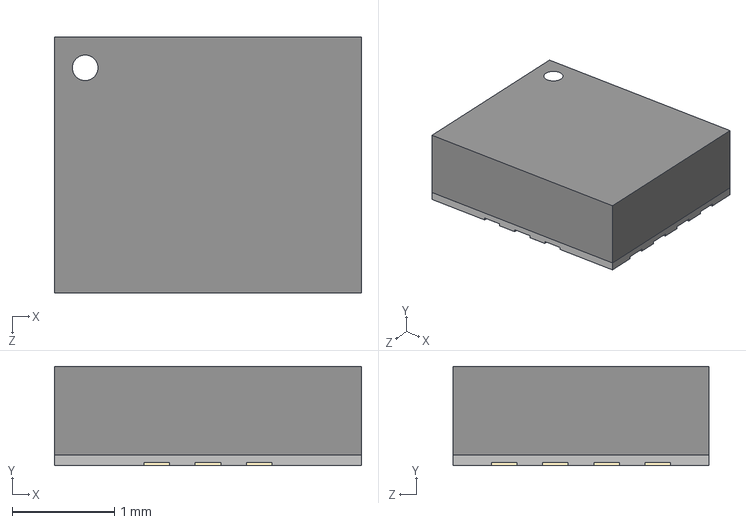
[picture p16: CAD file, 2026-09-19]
ARCHER/PCB Design/KiCAD 3D-Models/ICM-42688-P.step
3.00 x 0.97 x 2.50 mm

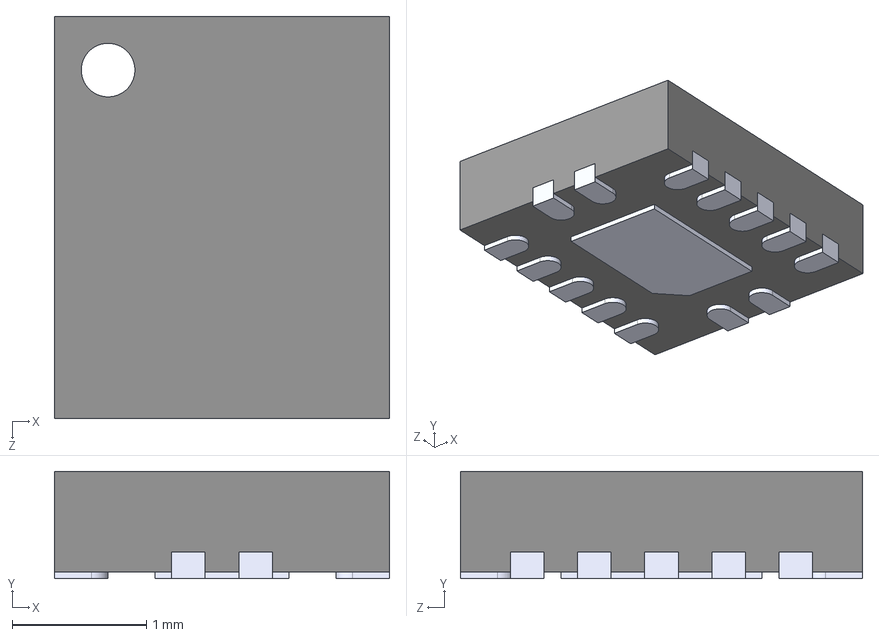
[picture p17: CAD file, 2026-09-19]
ARCHER/PCB Design/KiCAD 3D-Models/SN74AHC14BQAR.STEP
2.50 x 0.8 x 3.00 mm

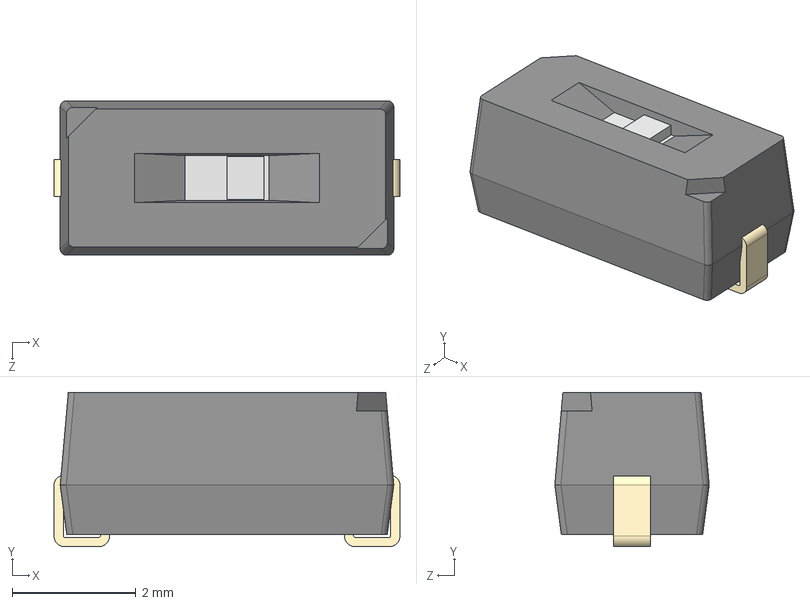
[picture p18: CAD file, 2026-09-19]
ARCHER/PCB Design/KiCAD 3D-Models/CHS-01TA--3DModel-STEP-269445.STEP
5.60 x 2.50 x 2.50 mm
CHS-01 body
pin^CHS-01xx
switch^CHS-01xx

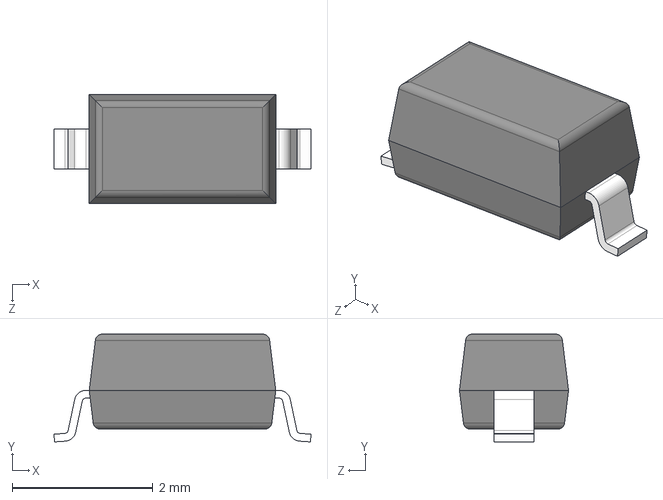
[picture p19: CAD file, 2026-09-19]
ARCHER/PCB Design/KiCAD 3D-Models/1N5819HW-7-F.step
3.65 x 1.53 x 1.55 mm

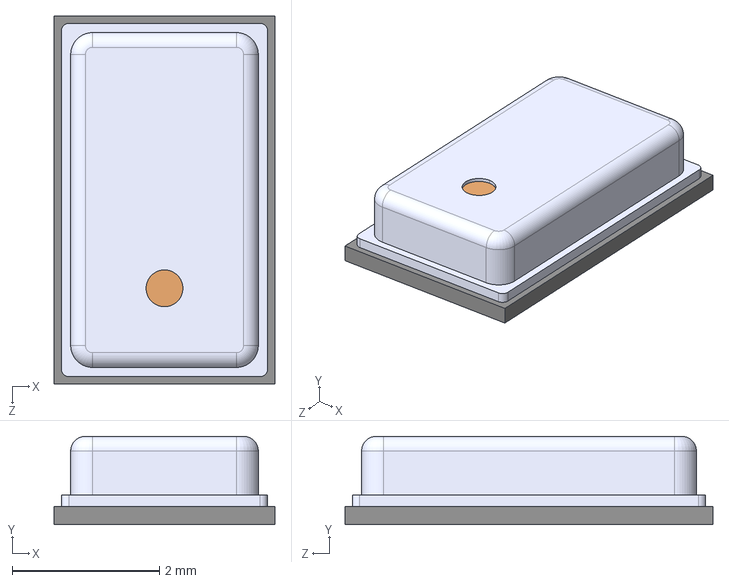
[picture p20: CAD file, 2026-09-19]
ARCHER/PCB Design/KiCAD 3D-Models/MPL3115A2.step
3.00 x 1.20 x 5.00 mm

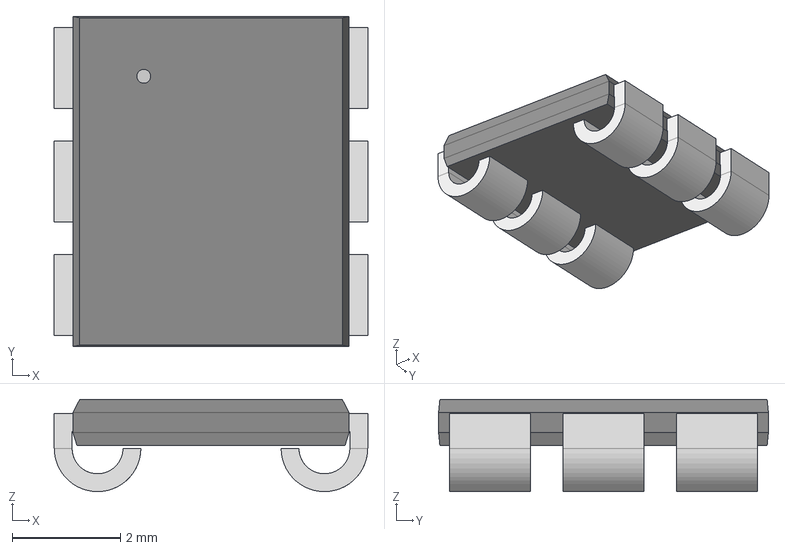
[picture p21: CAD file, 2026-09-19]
ARCHER/PCB Design/KiCAD 3D-Models/PLCC6_CLP6C-FKB_CRW.step
5.79 x 6.10 x 1.70 mm

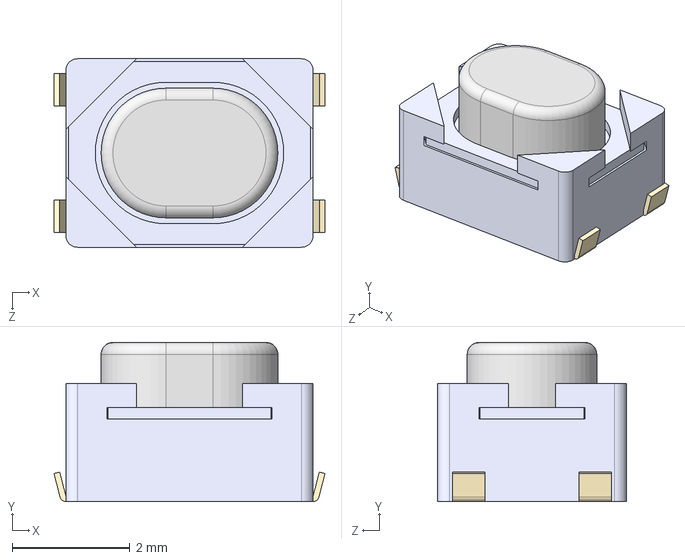
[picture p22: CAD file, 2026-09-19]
ARCHER/PCB Design/KiCAD 3D-Models/PTS810_SJM_250_SMTR_LFS.step
4.60 x 2.70 x 3.20 mm

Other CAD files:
ARCHER/PCB Design/KiCAD 3D-Models/GSB1C411101DS1HR.step
ARCHER/PCB Design/KiCAD 3D-Models/SSB44-E3_52T.STEP
ARCHER/PCB Design/KiCAD 3D-Models/ADXL375BCCZ-RL7.STEP
ARCHER/PCB Design/KiCAD 3D-Models/PMV37ENEAR.step
ARCHER/CAD Design/Antriebssektion 2 350 v3.f3d
ARCHER/CAD Design/Assembly CanSat - ASCENT Lite v1.0.0 v11.f3z
ARCHER/CAD Design/Assembly CanSat EV v2.f3z
ARCHER/CAD Design/Baugruppe Rakete v7.f3z
ARCHER/CAD Design/Baugruppe-Segmentverbinder-21.10.2024 v5.f3z
ARCHER/CAD Design/Connection-Ring-female-21.10.2024 v13.f3d
ARCHER/CAD Design/Connection-Ring-male-21.10.2024 v8.f3d
ARCHER/CAD Design/Servomotor - DS5160 v4.f3d
ARCHER/PCB Design/KiCAD 3D-Models/1-282837-4.step
ARCHER/PCB Design/KiCAD 3D-Models/1935284.stp
ARCHER/PCB Design/KiCAD 3D-Models/61300621121.step
ARCHER/PCB Design/KiCAD 3D-Models/AQ4020-01FTG-C.STEP
ARCHER/PCB Design/KiCAD 3D-Models/CP2102N-A02-GQFN28.step
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

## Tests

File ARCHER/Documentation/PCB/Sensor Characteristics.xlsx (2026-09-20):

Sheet: IMUs
 | BMI160 |  |  |  |  | MPU6500 |  |  |  | ICM-42688-P |  |  |  |  |  |  |  | ICM-45686
Accelerometer Specs
Measurement Range | 2g | 4g | 8g | 16g |  | 2g | 4g | 8g | 16g | 2g |  | 4g |  | 8g |  | 16g |  | 2g |  | 4g |  | 8g |  | 16g |  | 32g
Output Resolution | 16 Bits |  |  |  |  | 16 Bits |  |  |  | 16 bits |  |  |  |  |  |  |  | 16 bits
Sensitivity (Typical) | 16384 LSB/g | 8192 LSB/g | 4096 LSB/g | 2048 LSB/g |  | 16384 LSB/g | 8192 LSB/g | 4096 LSB/g | 2048 LSB/g | 16384 LSB/g |  | 8192 LSB/g |  | 4096 LSB/g |  | 2048 LSB/g |  | 16384 LSB/g |  | 8192 LSB/g |  | 4096 LSB/g |  | 2048 LSB/g |  | 1024 LSB/g
Sensitivity Change Due to Temperature | x | y |  | z |  | x | y | z |  | 0.005 %/°C |  |  |  |  |  |  |  | 0.01 %/°C
 | +- 0.03 %/K |  |  |  |  | +-0.026 %/C
0g Offset |  |  | +-0.040 g |  |  | +-0.06 g |  |  |  | ±20 mg |  |  |  |  |  |  |  | ±10 mg
Noise | 1.8 mg rms |  |  |  |  | Low Noise Mode: 300 ug/sqrt(Hz) |  |  |  | x and y-axis |  |  |  | z-axis |  |  |  | Bandwidth = 100 Hz
 |  |  |  |  |  | Programmable Lowpass Filter: 5 ... 260 Hz |  |  |  | 0.65 mg-rms |  |  |  | 0.70 mg-rms |  |  |  | 0.7 mg-rms |  |  |  |  |  | 0.8 mg-rms |  | 1.1 mg-rms
Operating Voltage Range (V_S or V_DD) | Min | Typical |  |  | Max | Min | Typical |  | Max | Min. |  | Typical |  |  |  | Max. |  | Min. |  | Typical |  |  |  | Max.
 | 1.71 V | 3.0 V |  |  | 3.6 V | 1.71 V | 1.8 V |  | 3.45 V | 1.71 V |  | 1.8 V |  |  |  | 3.6 V |  | 1.71 V |  | 1.8 V |  |  |  | 3.6 V
Interface Voltage Range (V_DD I/O) | 1.2 V | 2.4 V |  |  | 3.6 V | 1.71 V | 1.8 V |  | 3.45 V | 1.71 V |  | 1.8 V |  |  |  | 3.6 V |  | 1.08 V |  | 1.8 V |  |  |  | 3.6 V
Output Data Rate (ODR) | Min |  | Max |  |  | Min |  | Max |  | Min. |  |  |  | Max. |  |  |  | Low Noise Mode (LNM) |  |  |  | Low Power Mode (LPM)
 | 12.5 Hz |  | 1600 Hz |  |  | 4 Hz |  | 4000 Hz |  | 1.5625 Hz |  |  |  | 32000 Hz |  |  |  | Min.: 12.5 Hz |  | Max.: 6400 Hz |  | Min.: 1.5625 Hz |  | Max.: 400 Hz
Current Consumption | Accelerometer |  | Gyroscope | Both (On) | None (Stby) | Accelerometer | Gyroscope | Both (On) | None (Stby) | 3-Axis Accel. |  | 3-Axis Gyro |  | 6-Axis Accel. + Gyro |  | Sleep Mode |  | 6-axis Accel. + Gyro |  | 3-axis Accel. | 3-axis Gyro | 6-axis Accel. + Gyro. |  | 3-axis Accel. | 3-axis Gyro | Sleep Mode
 | 300 uA |  | 900 uA | 990 uA | 10 uA | 0.45 mA | 3.2 mA | 3.4 mA | 1.6 mA | 0.28 mA |  | 0.73 mA |  | 0.88 mA |  | 7.5 uA |  | 420 uA |  | 120 uA | 360 uA | 220 uA |  | 67 uA | 210 uA | 2.2 uA
Power Consumption | For Typical VDD = 3.0 V |  |  |  |  | For Typical VDD = 1.8 V |  |  |  | For typical VDD = 3.3 V |  |  |  |  |  |  |  | For typical VDD = 3.3 V
 | 0.90 mW |  | 2.70 mW | 2.97 mW | 0.03 mW | 0.81 mW | 5.76 mW | 6.12 mW | 2.88 mW | 0.924 mW |  | 2.409 mW |  | 2.904 mW |  | 24.75 uW |  | 1.386 mW |  | 396 uW | 1.188 mW | 726 uW |  | 221.1 uW | 693 uW | 7.26 uW
Temperature Range | -40 ... +85 C |  |  |  |  | -40 ... +85 C |  |  |  | -40 ...+85°C |  |  |  |  |  |  |  | -40 ...+85°C
Weight | - |  |  |  |  | - |  |  |  | - |  |  |  |  |  |  |  | -
Gyro Specs
Measurement Range | 125 deg/s | 250 deg/s | 500 deg/s | 1000 deg/s | 2000 deg/s | 250 deg/s | 500 deg/s | 1000 deg/s | 2000 deg/s | 15.625 deg/s | 31.25 deg/s | 62.5 deg/s | 125 deg/s | 250 deg/s | 500 deg/s | 1000 deg/s | 2000 deg/s | 15.625 deg/s | 31.25 deg/s | 62.5 deg/s | 125 deg/s | 250 deg/s | 500 deg/s | 1000 deg/s | 2000 deg/s | 4000 deg/s
Sensitivity | 262.4 LSB/deg/s | 131.2 LSB/deg/s | 65.6 LSB/deg/s | 32.8 LSB/deg/s | 16.4 LSB/deg/s | 131 LSB/deg/s | 65.5 LSB/deg/s | 32.4 LSB/deg/s | 16.4 LSB/deg/s | 2097.2 LSB/(deg/s) | 1048.6 LSB/(deg/s) | 524.3 LSB/(deg/s) | 262 LSB/(deg/s) | 131 LSB/(deg/s) | 65.5 LSB/(deg/s) | 32.8 LSB/(deg/s) | 16.4 LSB/(deg/s) | 2097.2 LSB/(deg/s) | 1048.6 LSB/(deg/s) | 524.3 LSB/(deg/s) | 262 LSB/(deg/s) | 131 LSB/(deg/s) | 65.5 LSB/(deg/s) | 32.8 LSB/(deg/s) | 16.4 LSB/(deg/s) | 8.2 LSB/(deg/s)
Sensitivity Change Due to Temperature | +-0.02 %/K |  |  |  |  | +-3 % |  |  |  | 0.005 %/°C |  |  |  |  |  |  |  | 0.01 %/°C
Zero-rate Offset | +-3 deg/s |  |  |  |  | +-5 deg/s |  |  |  | 0.5 deg/s |  |  |  |  |  |  |  | 0.3 deg/s
Noise | 0.07 deg/s rms |  |  |  |  | 0.1 deg/s rms |  |  |  | 0.028 deg/s-rms |  |  |  |  |  |  |  | 0.038 deg/s-rms
Magnetometer Specs

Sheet: Accelerometer
 | ADXL345 |  |  |  | ADXL343 |  |  |  | KX134
Accelerometer Specs
Measurement Range | 2g | 4g | 8g | 16g | 2g | 4g | 8g | 16g | 8g | 16g | 32g | 64g
Output Resolution | 10 Bits | 11 Bits | 12 Bits | 13 Bits | 10 Bits | 11 Bits | 12 Bits | 13 Bits | 16 Bits
Sensitivity (Typical) | 256 LSB/g | 128 LSB/g | 64 LSB/g | 32 LSB/g | 256 LSB/g | 128 LSB/g | 64 LSB/g | 32 LSB/g | 4096 LSB/g | 2048 LSB/g | 1024 LSB/g | 512 LSB/g
Sensitivity Change Due to Temperature | x | y | z |  | x | y | z |  | x | y | z
 | +-0.01 %/C |  |  |  | +-0.01 %/C |  |  |  | 0.01 %/C |  | 0.03 %/C
0g Offset | +-0.15 g |  | +-0.25 g |  | +-0.035 g |  |  |  | +-0.025 g
Noise | 0.75 LSB rms |  | 1.1 LSB rms |  | 1.1 LSB rms |  |  |  | 0.7 mg rms
Operating Voltage Range (V_S or V_DD) | Min | Typical |  | Max | Min | Typical |  | Max | Min | Typical |  | Max
 | 2.0 V | 2.5 V |  | 3.6 V | 2.0 V | 2.5 V |  | 3.6 V | 1.7 V | 2.5 V |  | 3.6 V
Interface Voltage Range (V_DD I/O) | 1.7 V | 1.8 V |  | V_DD | 1.7 V | 1.8 V |  | V_DD | 1.2 V | - |  | 3.6 V
Output Data Rate (ODR) | Min |  | Max |  | Min |  | Max |  | Min | Typical |  | Max
 | 0.1 Hz |  | 3200 Hz |  | 0.1 Hz |  | 3200 Hz |  | 0.781 Hz | 50 Hz |  | 25600 Hz
Current Consumption | ODR >= 100 Hz |  | ODR < 10 Hz | Standby | ODR >= 100 Hz |  | ODR < 10 Hz | Standby | Performance |  | Low Power | Standby
 | 140 uA |  | 30 uA | 0.1 uA | 140 uA |  | 30 uA | 0.1 uA | 148 uA |  | 0.53 uA | 0.5 uA
Power Consumption | Min | Typical |  | Max | Min | Typical |  | Max | For VDD = 3.3 V
 | 0.28 mW | 0.35 mW |  | 0.5 mW | 0.28 mW | 0.35 mW |  | 0.5 mW | 0.488 mW |  | 1.749 uW | 1.65 uW
Temperature Range | -40 ... +85 C |  |  |  | -40 ... +85 C |  |  |  | -40 ... +105 C
Weight | 30 mg |  |  |  | 30 mg |  |  |  | -

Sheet: Pressure Sensors
 | HSCMAND015PASA5 |  |  |  | MS561101BA03-50 |  |  |  |  | MPL3115A2ST1 |  |  |  |  |  | MS560702BA03-50
Pressure Specs |  |  |  |  |  |  |  |  |  | further info for I2C see data sheet
Measurement Range | 1.6 mbar - 1.0 bar | 160 Pa - 100 kPa |  | 0.02 psi - 14.5 psi | 10 mbar - 1200 mbar* | 1 kPa - 120 kPa |  | 0,15 psi - 17,4 psi |  | 0,2 bar - 1,2 bar* |  | 20 kPa - 120 kPa |  | 2.9 psi - 17.4 psi |  | 10 mbar - 2000 mbar* | 1 kPa - 200 kPa |  | 0,15 psi - 29 psi
Pressure Accuracy | ±0.25%FSS BFSL |  |  |  | ±2.5 mbar |  |  |  |  | ±0.4 kPa |  |  |  |  |  | Min |  |  | Max
 |  |  |  |  |  |  |  |  |  |  |  |  |  |  |  | -1.5 mbar |  |  | 1.5 mbar
Pressure Resolution | 12 bits |  |  |  | 24 bits |  |  |  |  | 20 bits |  |  |  |  |  | 24 bits
Long term stability | N/A |  |  |  | ±1 mbar/yr |  |  |  |  | ±0.1 kPa/yr |  |  |  |  |  | ±1 mbar/yr
Max Pressure | N/A |  |  |  | 6 bar | 600 kPa |  | 87 psi |  | 5 bar |  | 500 kPa |  | 72,5 psi |  | 6 bar | 600 kPa |  | 87 psi
Noise | N/A |  |  |  | 1.2 (4096), 1,8 (2048), 2.7 (1024), 4.2 (512), 6.5 (256) |  |  |  | Pa (OSR) | 1x oversample |  |  | 128x oversample |  |  | 2.4 (4096), 3.6 (2048), 5.4 (1024), 8.4 (512), 13.0 (256) |  |  |  | Pa (OSR)
 |  |  |  |  |  |  |  |  |  | 19 Pa RMS |  |  | 1.5 Pa RMS
Suply Voltage Range (V_S or V_DD) | Min* | Typical |  | Max | Min | Typical |  | Max |  | Min |  | Typical |  | Max |  | Min | Typical |  | Max
 | 3.0 | 3.3 V |  | 3.6 V | 1.8 V | 3.0 V |  | 3.6 V |  | 1.95 V |  | 2.5 V |  | 3.6 V |  | 1.8 V | 3.0 V |  | 3.6 V
Interface Supply Voltage (V_DDIO) | N/A |  |  |  | N/A |  |  |  |  | Min |  | Typical |  | Max |  | N/A
 |  |  |  |  |  |  |  |  |  | 1.62 V |  | 1.8 V |  | 3.6 V
Output Data Rate (ODR) | SPI (Max) |  | I2C (Max) |  | SPI (Max) |  | I2C (Max) |  |  | I2C f_SCL 1 |  |  | I2C f_SCL 2 |  |  | SPI (Max) |  | I2C (Max)
 | 800 kHz |  | 400 kHz |  | 20 MHz |  | 400 kHz |  |  | 400 kHz |  |  | 4 MHz |  |  | 20 MHz |  | 400 kHz
Current Consumption | Supply (typical) |  | Supply (max) |  | Supply*** |  |  | Peak | Standby | Operational** |  |  |  | Peak | Standby | Supply |  |  | Peak | Standby
 | 3.1 mA |  | 3.9 mA |  | 12.5 (4096)****, 6.3 (2048), 3.2 (1024), 1.7 (512), 0.9 (256) μA |  |  | 1.4 mA | 0.14 μA | 8.5 μA (1) | 40 μA (16) | 265 μA (128) |  | 2 mA | 2 μA | 12.5 (4096)***, 6.3 (2048), 3.2 (1024), 1.7 (512), 0.9 (256) μA |  |  | 1.4 mA | 0.14 μA
Power Consumption | 10.23 mW |  | 12.87 mW |  | 41.25 uW |  |  | 4.62 mW | 0.462 uW | 844,8 uW |  |  |  | 6.6 mW | 6.6 uW | 41.25 uW |  |  | 4.62 mW | 0.462 uW
Temperature Range | Min |  |  | Max | Min | Typical |  | Max |  | Min |  |  |  | Max |  | Min | Typical |  | Max
 | -20°C |  |  | +85°C | -40°C | +25°C |  | +85°C |  | -40°C |  |  |  | +85°C |  | -40°C | +25°C |  | +85°C
Power consumption***** | Max |  |  |  | Supply |  | Standby |  |  | Operational |  |  | Standby |  |  | Supply |  | Standby
 | 12,87 mW |  |  |  | 41,25 μW |  | 0,462 μW |  |  | 874,5 μW |  |  | 6,6 μW |  |  | 41,25 μW |  | 0,462 μW
Weight | - |  |  |  | - |  |  |  |  | N/A |  |  |  |  |  | N/A
Temperature Specs
Measurement Range | N/A |  |  |  | -40 … +85°C |  |  |  |  | -40…+85°C |  |  |  |  |  | -40 … +85°C
Accuracy |  |  |  |  | Min | -20°C…85°C |  | Max |  | ±3°C |  |  |  |  |  | Min | -20°C…85°C |  | Max
 |  |  |  |  | -0.8°C | ±2.0°C |  | +0.8°C |  |  |  |  |  |  |  | -0.8°C | ±2.0°C |  | +0.8°C
Resolution |  |  |  |  | 24 bits |  |  |  |  | 12 bits |  |  |  |  |  | 24 bits
Noise |  |  |  |  | 0.002°C (4096), 0.003 (2048), 0.005 (1024), 0.008 (512), 0.012 (256) |  |  |  |  |  |  |  |  |  |  | 0.002°C (4096), 0.003 (2048), 0.005 (1024), 0.008 (512), 0.012 (256)
Max Soldering Temperature |  |  |  |  | 250°C @ 40 sec max |  |  |  |  |  |  |  |  |  |  | 250°C @ 40 sec max
I2C Address |  |  |  |  |  |  |  |  |  | 0x60

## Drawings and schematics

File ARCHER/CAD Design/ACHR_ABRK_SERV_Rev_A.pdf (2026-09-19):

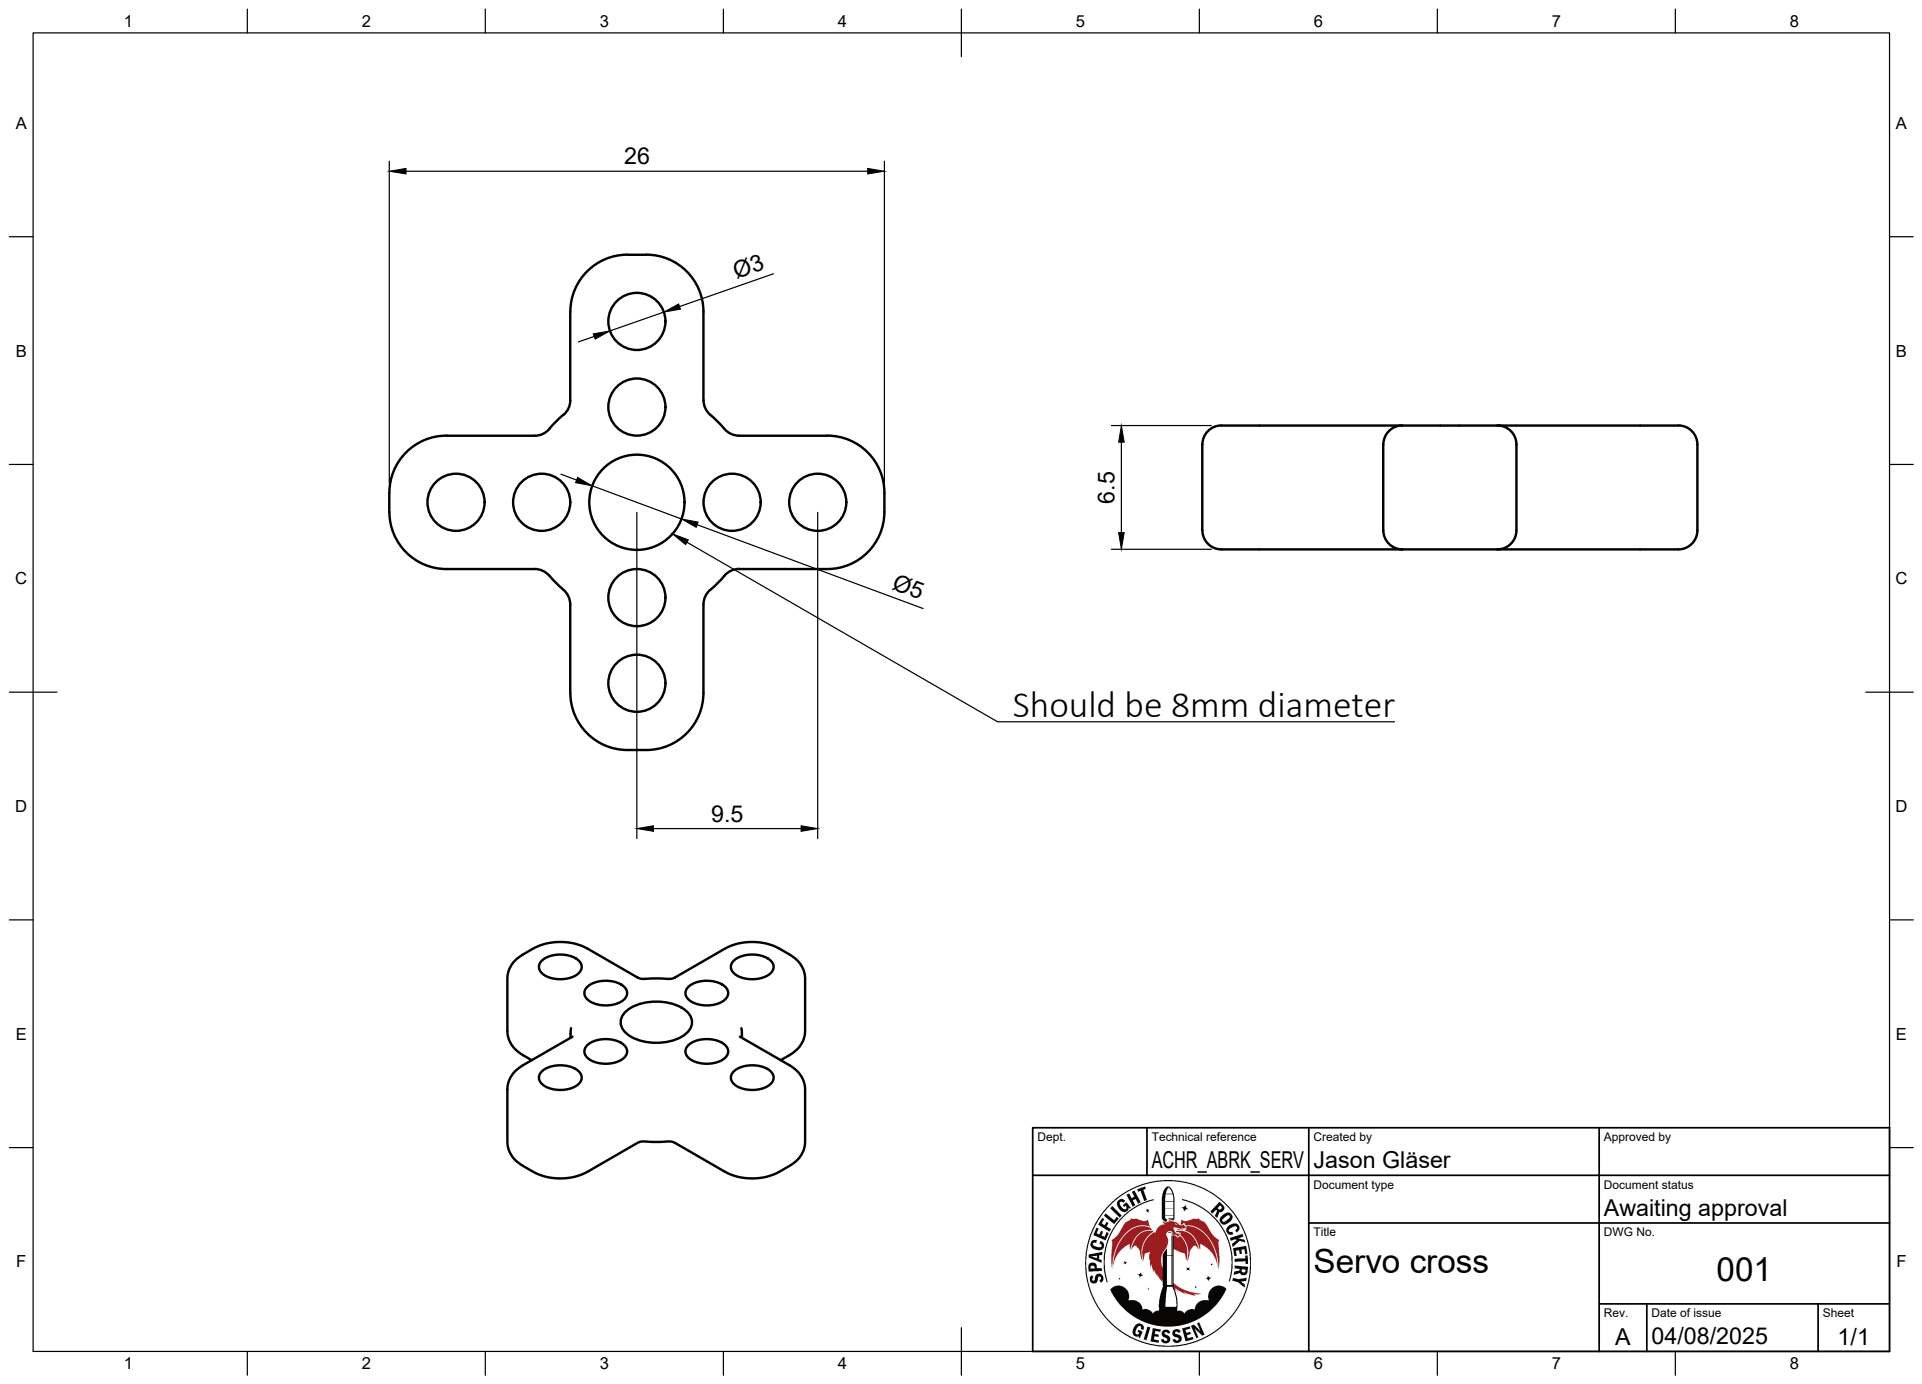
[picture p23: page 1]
Title; DWG No.; Rev.; Date of issue; Sheet; Servo cross

Should be 8mm diameter

Dept. | Technical reference ACHR_ABRK_SERV | Created by Jason Gläser | Approved by

Document type | Document status Awaiting approval

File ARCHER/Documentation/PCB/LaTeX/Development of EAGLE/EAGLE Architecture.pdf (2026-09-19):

## EAGLE

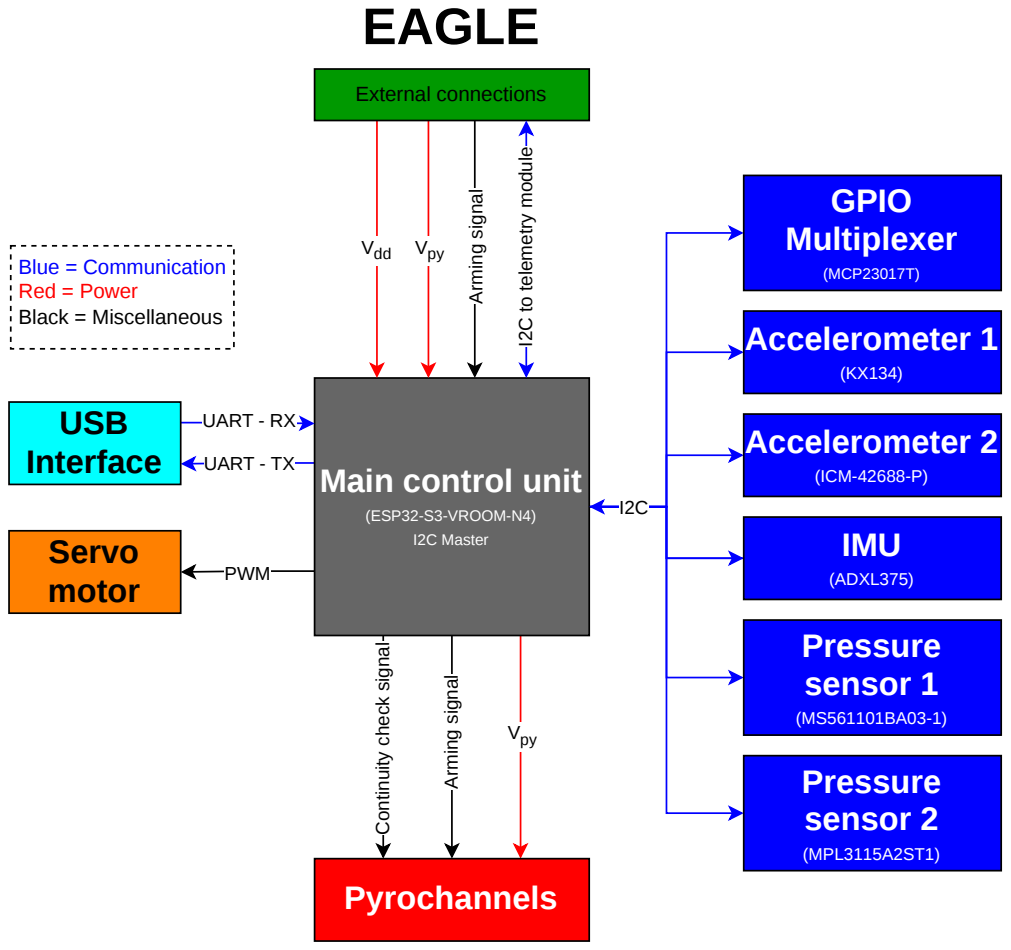
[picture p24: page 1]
UART - TX; Arming signal; Vpy; PWM; (ESP32-S3-VROOM-N4) I2C Master; Pressure sensor 2; (MPL3115A2ST1); Pressure sensor 1; Vdd; Accelerometer 1; Accelerometer 2; (ICM-42688-P); IMU; (ADXL375); GPIO Multiplexer; (MCP23017T); USB; UART - RX; Interface; Pyrochannels; Blue = Communication Red = Power Black = Miscellaneous; Servo motor

External connectionsI2C to telemetry module

Main control unit

Continuity check signal

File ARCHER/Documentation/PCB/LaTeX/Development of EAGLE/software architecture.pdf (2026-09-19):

### Setup

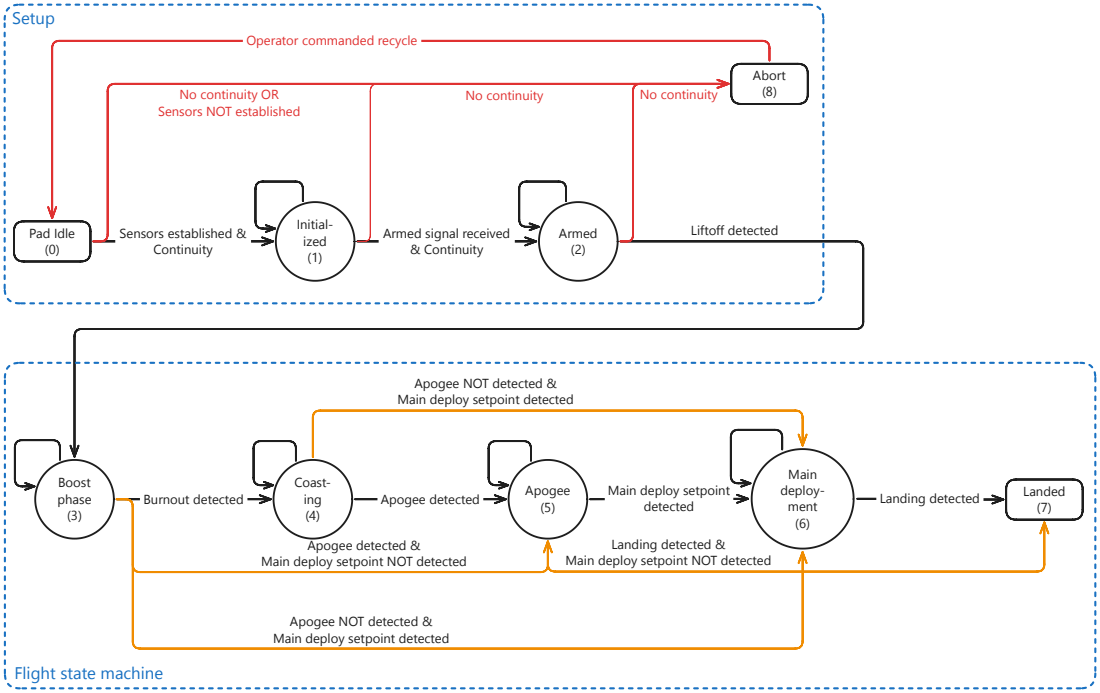
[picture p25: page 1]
Pad Idle (0); Sensors established & Continuity; Initial- ized (1); Armed (2); Boost phase (3); Coast- ing (4); Burnout detected; Apogee; (5) Apogee detected; Main deploy- ment (6); detected; Landing detected; Apogee detected &; Landing detected &; Landed (7); Abort; No continuity OR; No continuity; Liftoff detected

Operator commanded recycle

Sensors NOT established

Armed signal received
& Continuity

Apogee NOT detected &
Main deploy setpoint detected

Main deploy setpoint

Main deploy setpoint NOT detected

Flight state machine

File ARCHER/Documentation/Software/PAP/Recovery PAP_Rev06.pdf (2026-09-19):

# Setup

# Pre-flight loop

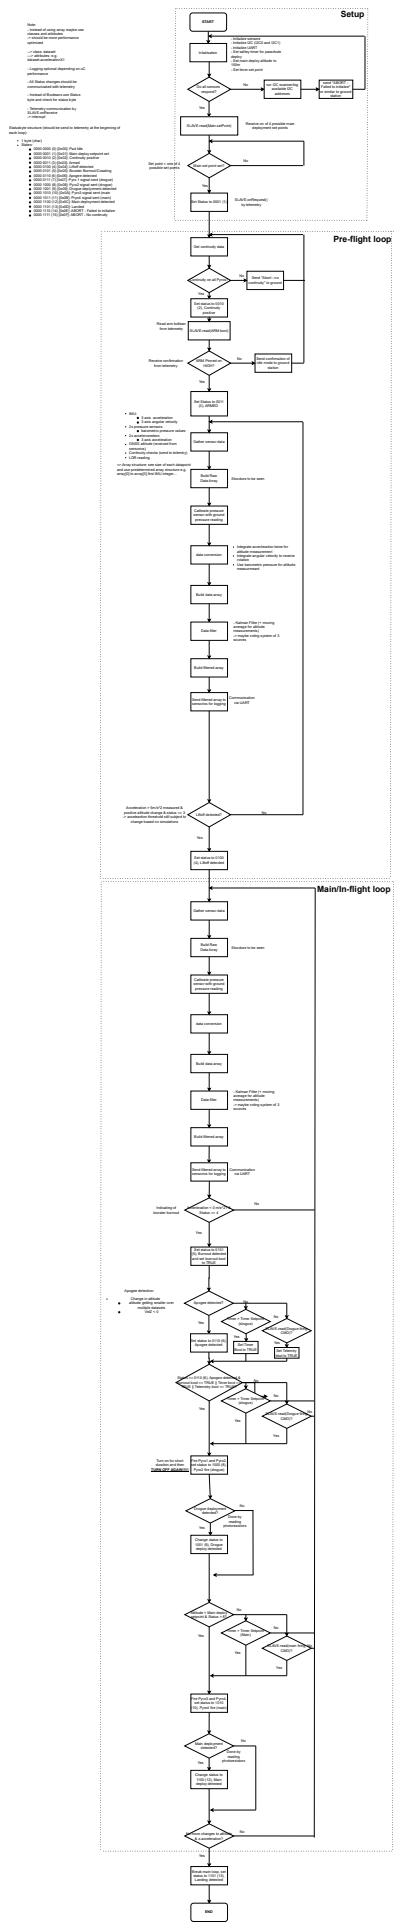
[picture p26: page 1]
--> class: dataset ---> attributes: e.g. dataset.accelerationX1; 1 byte (char) States:; START; Initalisation; send "ABORT -; Yes; SLAVE.read(Main.setPoint); Receive on of 4 possible main; Send confirmation of; SLAVE.onRequest() by telemetry; Build Raw; Data Array; Structure to be seen; data conversion; Data filter; IMU:; 2x pressure sensors:; 2x accelerometers: 3 axis acceleration; Liftoff detected?; Indicating of booster burnout; Accerleration < 0 m/s^2? & Status == 4; Communication via UART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

Note:
- Instead of using array maybe use
classes and attributes
-> should be more performance
optimized

- Initialize sensore
- Initialize I2C (I2C0 and I2C1)
- Initialize UART
- Set saftey timer for parachute
deploy
- Set main deploy altitude to
- Set timer set point

- Logging optional depending on uC
performance

- All Status changes should be
communicated with telemetry

run I2C scanner/log
available I2C
addreses

Do all sensors
respond?

Failed to initialize"
or similar to ground
station

- Instead of Booleans use Status
byte and check for status byte

- Telemetry communication by
SLAVE.onReceive
-> interrupt

Statusbyte structure (should be send to telemetry at the beginning of
each loop):

deployment set points

0000 0000 (0) [0x00]: Pad Idle
0000 0001 (1) [0x01]: Main deploy setpoint set
0000 0010 (2) [0x02]: Continuity positive
0000 0011 (3) [0x03]: Armed
0000 0100 (4) [0x04]: Liftoff detected
0000 0101 (5) [0x05]: Booster Burnout/Coasting
0000 0110 (6) [0x06]: Apogee detected
0000 0111 (7) [0x07]: Pyro 1 signal sent (drogue)
0000 1000 (8) [0x08]: Pyro2 signal sent (drogue)
0000 1001 (9) [0x09]: Drogue deplyoment detected
0000 1010 (10) [0x0A]: Pyro3 signal sent (main
0000 1011 (11) [0x0B]: Pryo4 signal sent (main)
0000 1100 (12) [0x0C]: Main deployment detected
0000 1101 (13) [0x0D]: Landed
0000 1110 (14) [0x0E]: ABORT - Failed to initialize
0000 1111 (15) [0x0F]: ABORT - No continuity

Set point = one of 4
possible set points

Main set point set?

Set Status to 0001 (1)

Get continuity data

continuity" to ground

Continuity on all Pyros?

Set status to 0010
(2), Continuity
positive

Read arm bollean
from telemetry

SLAVE.read(ARM bool)

ARM Pinned on
HIGH?

idle mode to ground

Set Status to 0011
(3), ARMED

3 axis acceleration
3 axis angular velocity

barometric pressure values

Gather sensor data

GNSS altitude (received from
sensorics)
Continuity checks (send to telemtry)
LDR reading

=> Array structure: see size of each datapoint
and use predetermined array structure e.g.
array[0] to array[3] first IMU integer...

Calibrate pressure
sensor with ground
pressure reading

Integrate accerleration twice for
altitude measurement
Integrate angular velocity to receive
rotation
Use barometric pressure for altitude
measurmeant

Build data array

- Kalman Filter (+ moving
average for altitude
measurements)
-> maybe voting system of 3
sources

Build filtered array

Send filtered array to
sensorics for logging

Acceleration > 5m/s^2 measured &
positive altitude change & status == 3
-> acceleartion threshold still subject to
change based on simulations

Set status to 0100
(4), Liftoff detected

Main/In-flight loop

Set status to 0101
(5), Burnout detected
and set burnout bool
to TRUE

Change in altitude
altitude getting smaller over
multiple datasets
VelZ < 0

Timer > Timer Setpoint
(drogue)

SLAVE.read(Drogue firing

Set status to 0110 (6),
Apogee detected

bbol to TRUE

Status == 0110 (6), Apogee detected &
burnout bool == TRUE || Timer bool ==
TRUE || Telemetry bool == TRUE?

Turn on for short
duration and then
TURN OFF AGAIN!!!!!

Fire Pyro1 and Pyro2,
set status to 1000 (8),
Pyro2 fire (drogue)

Change status to
1001 (9), Drogue
deploy detected

Attitude < Main deploy
setpoint & Status > 8?

SLAVE.read(main firing

Fire Pyro3 and Pyro4,
set status to 1010
(10), Pyro4 fire (main)

1100 (12), Main

No more changes to altitude
& z-acceleration?

Break main loop, set
status to 1101 (13),
Landing detected

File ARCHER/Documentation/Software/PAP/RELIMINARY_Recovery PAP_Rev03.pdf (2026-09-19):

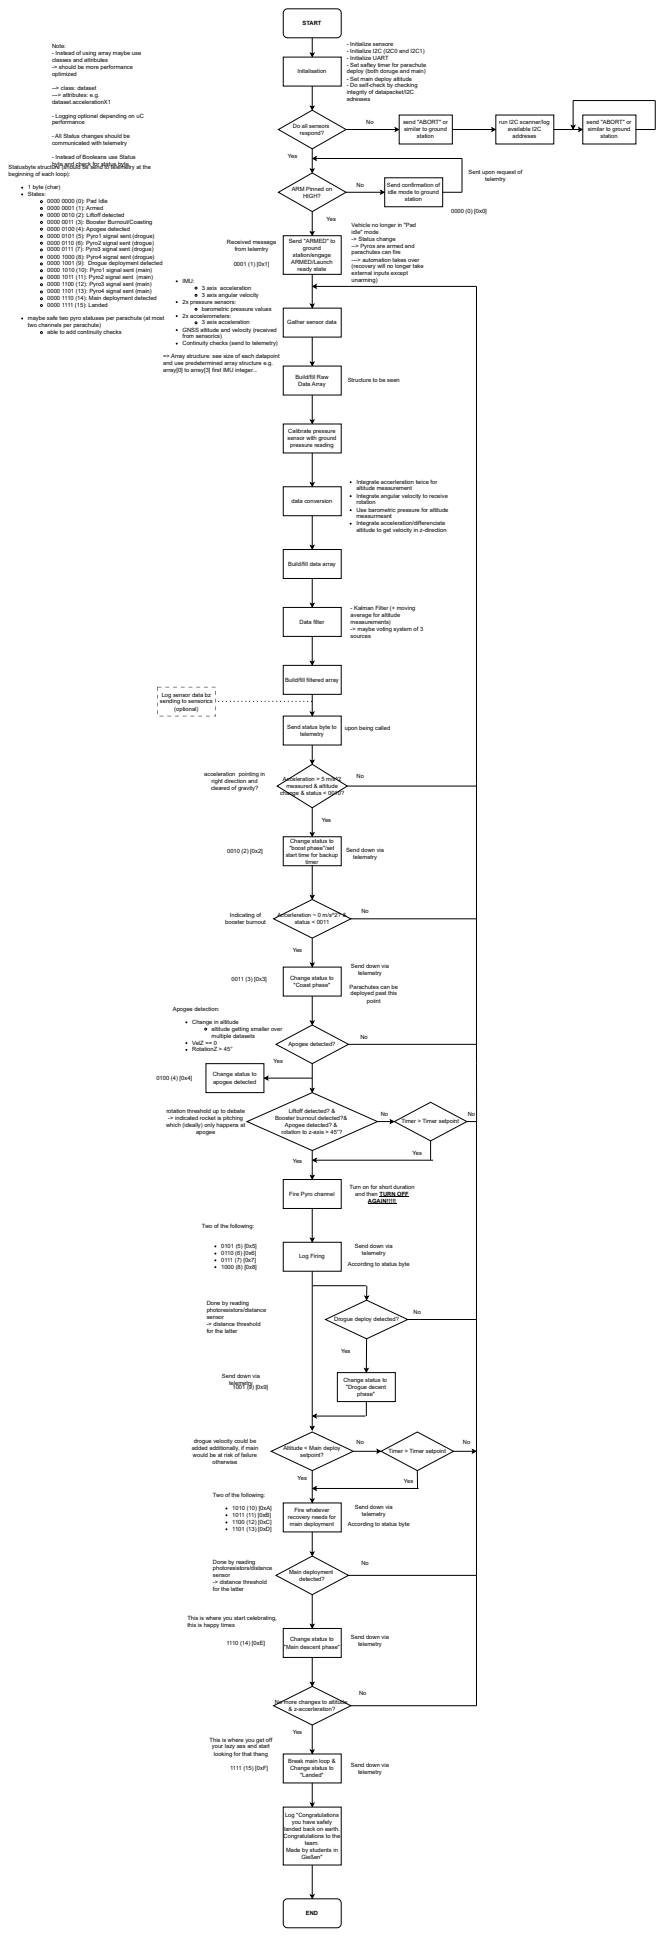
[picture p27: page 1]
START; Initalisation; send "ABORT" or; Data Array; Structure to be seen; data conversion; Yes; Send confirmation of; --> class: dataset ---> attributes: e.g. dataset.accelerationX1; Acceleration > 5 m/s^2 measured & altitude change & status < 0010?; Data filter; Received message from telemtry; Accerleration ~ 0 m/s^2? & status < 0011; Apogee detected?; apogee; Log Firing; Main deployment detected?; END; Send down via telemetry; Apogee detection:; apogee detected 0100 (4) [0x4]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

Note:
- Instead of using array maybe use
classes and attributes
-> should be more performance
optimized

- Initialize sensore
- Initialize I2C (I2C0 and I2C1)
- Initialize UART
- Set saftey timer for parachute
deploy (both doruge and main)
- Set main deploy altitude
- Do self-check by checking
integrity of datapacket/I2C
adresses

- Logging optional depending on uC
performance

send "ABORT" or
similar to ground
station

run I2C scanner/log
available I2C
addreses

Do all sensors
respond?

- All Status changes should be
communicated with telemetry

- Instead of Booleans use Status
byte and check for status byte

Statusbyte structure (should be send to telemetry at the
beginning of each loop):

Sent upon request of
telemtry

1 byte (char)
States:
0000 0000 (0): Pad Idle
0000 0001 (1): Armed
0000 0010 (2): Liftoff detected
0000 0011 (3): Booster Burnout/Coasting
0000 0100 (4): Apogee detected
0000 0101 (5): Pyro1 signal sent (drogue)
0000 0110 (6): Pyro2 signal sent (drogue)
0000 0111 (7): Pyro3 signal sent (drogue)
0000 1000 (8): Pyro4 signal sent (drogue)
0000 1001 (9): Drogue deployment detected
0000 1010 (10): Pyro1 signal sent (main)
0000 1011 (11): Pyro2 signal sent (main)
0000 1100 (12): Pyro3 signal sent (main)
0000 1101 (13): Pyro4 signal sent (main)
0000 1110 (14): Main deployment detected
0000 1111 (15): Landed

ARM Pinned on
HIGH?

idle mode to ground

Vehicle no longer in "Pad
idle" mode
-> Status change
--> Pyros are armed and
parachutes can fire
---> automation takes over
(recovery will no longer take
external inputs except
unarming)

Send "ARMED" to
ground
station/engage
ARMED/Launch
ready state

IMU:
3 axis acceleration
3 axis angular velocity
2x pressure sensors:
barometric pressure values
2x accelerometers:
GNSS altitude and velocity (received
from sensorics)
Continuity checks (send to telemetry)

maybe safe two pyro statuses per parachute (at most
two channels per parachute)
able to add continuity checks

Gather sensor data

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

Build/fill Raw

Calibrate pressure
sensor with ground
pressure reading

Integrate accerleration twice for
altitude measurement
Integrate angular velocity to receive
rotation
Use barometric pressure for altitude
measurmeant
Integrate acceleration/differenciate
altitude to get velocity in z-direction

Build/fill data array

- Kalman Filter (+ moving
average for altitude
measurements)
-> maybe voting system of 3
sources

Build/fill filtered array

Log sensor data bz
sending to sensorics
(optional)

Send status byte to
telemetry

upon being called

acceleration pointing in
right direction and
cleared of gravity?

Change status to
"boost phase"/set
start time for backup
timer

Send down via

No Indicating of
booster burnout

"Coast phase"

Parachutes can be
deployed past this
poiint

Change in altitude
altitude getting smaller over
multiple datasets
VelZ == 0
RotationZ > 45°

rotation threshold up to debate
-> indicated rocket is pitching
which (ideally) only happens at

Liftoff detected? &
Booster burnout detected?&
Apogee detected? &
rotation to z-axis > 45°?

Timer > Timer setpoint

Turn on for short duration
and then TURN OFF
AGAIN!!!!!

Fire Pyro channel

Two of the following:

According to status byte

Done by reading
photoresistors/distance
sensor
-> distance threshold
for the latter

Drogue deploy detected?

"Drogue decent
phase"

drogue velocity could be
added additionally, if main
would be at risk of failure
otherwise

Altitude < Main deploy
setpoint?

Fire whatever
recovery needs for
main deployment

This is where you start celebrating,
this is happy times

"Main descent phase"

No more changes to altitude
& z-accerleration?

This is where you get off
your lazy ass and start
looking for that thang

Break main loop &
"Landed"

Log "Congratulations
you have safely
landed back on earth.
Congratulations to the

team.
Made by students in
Gießen"

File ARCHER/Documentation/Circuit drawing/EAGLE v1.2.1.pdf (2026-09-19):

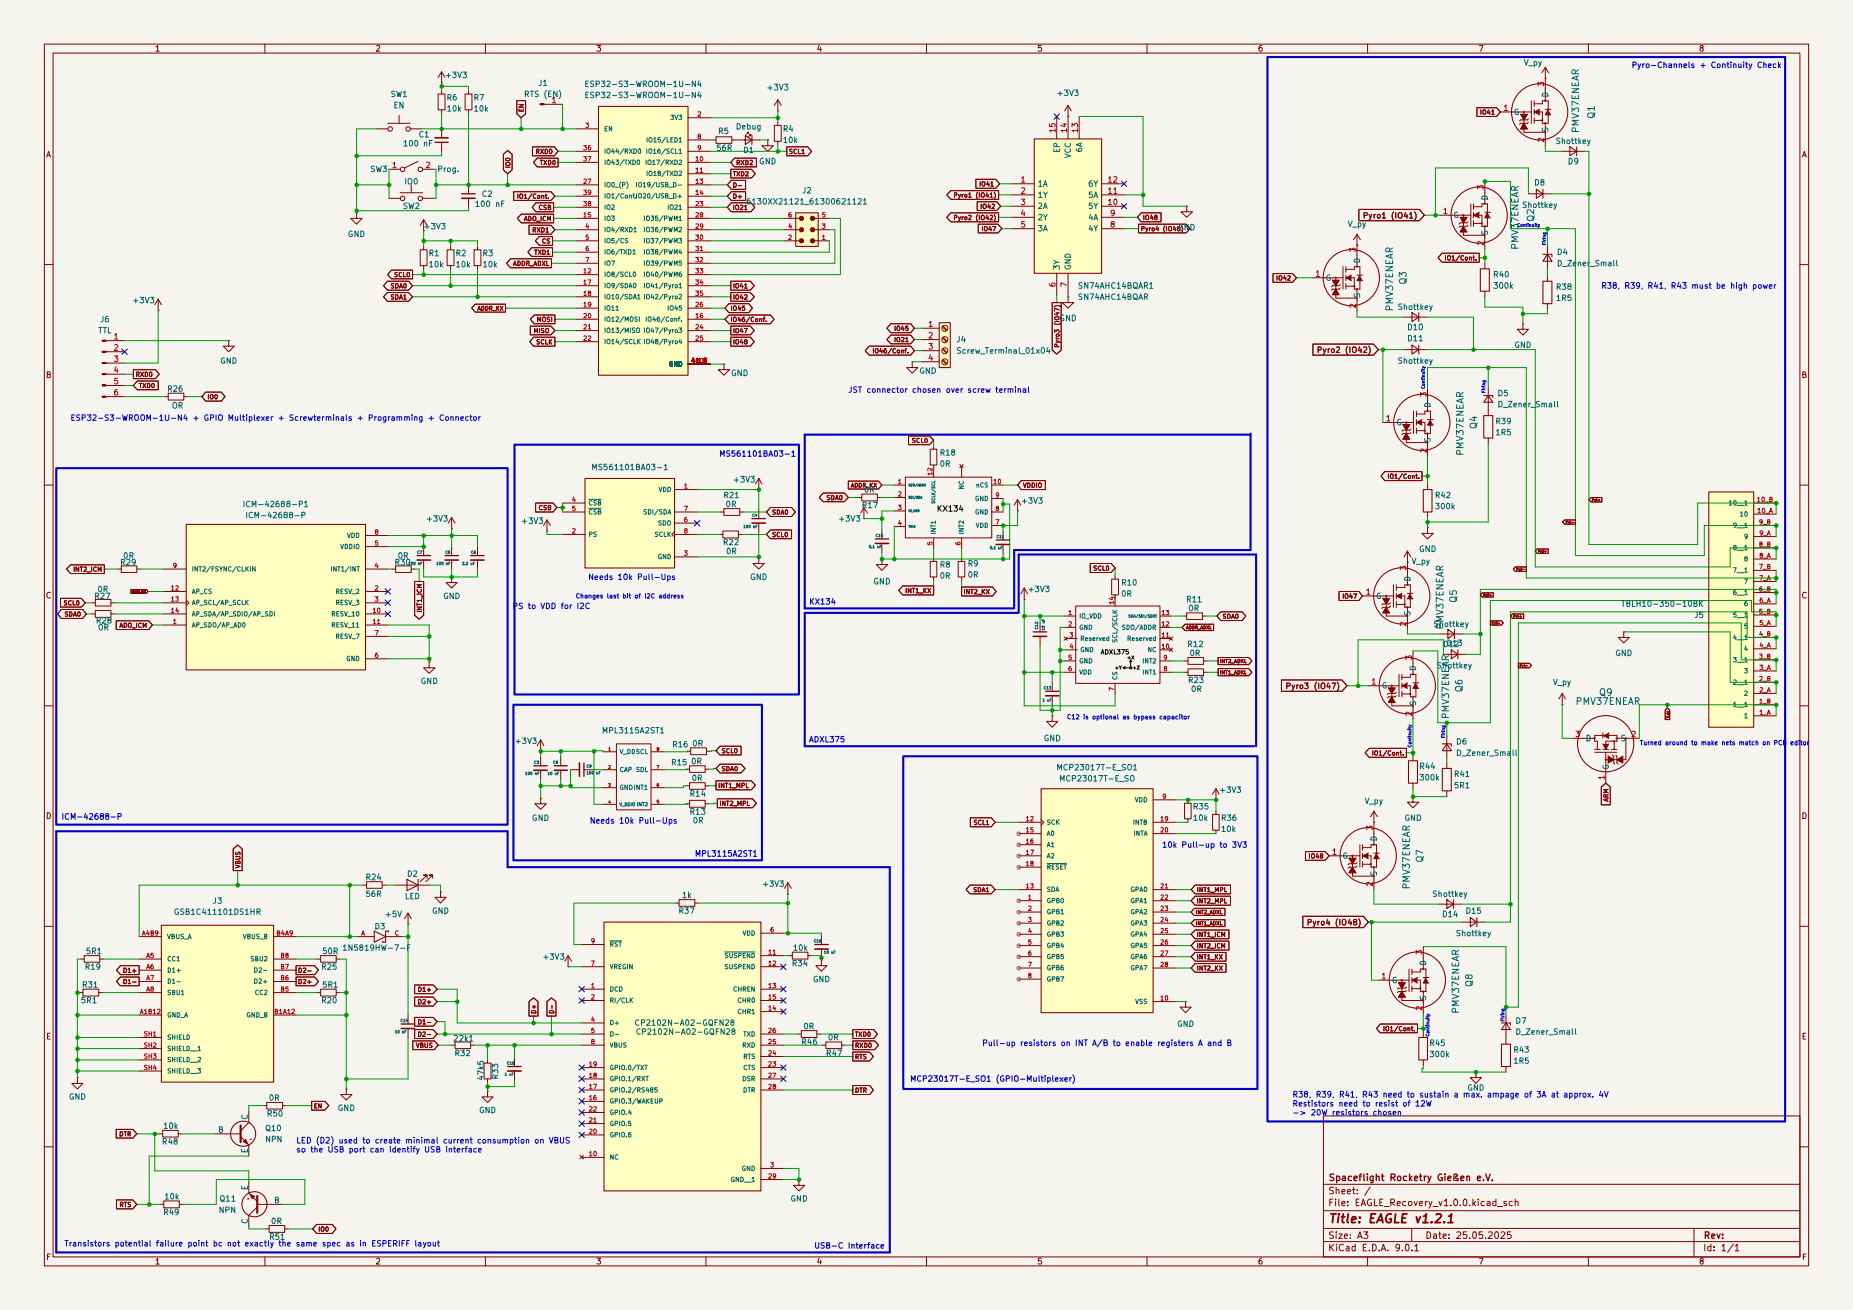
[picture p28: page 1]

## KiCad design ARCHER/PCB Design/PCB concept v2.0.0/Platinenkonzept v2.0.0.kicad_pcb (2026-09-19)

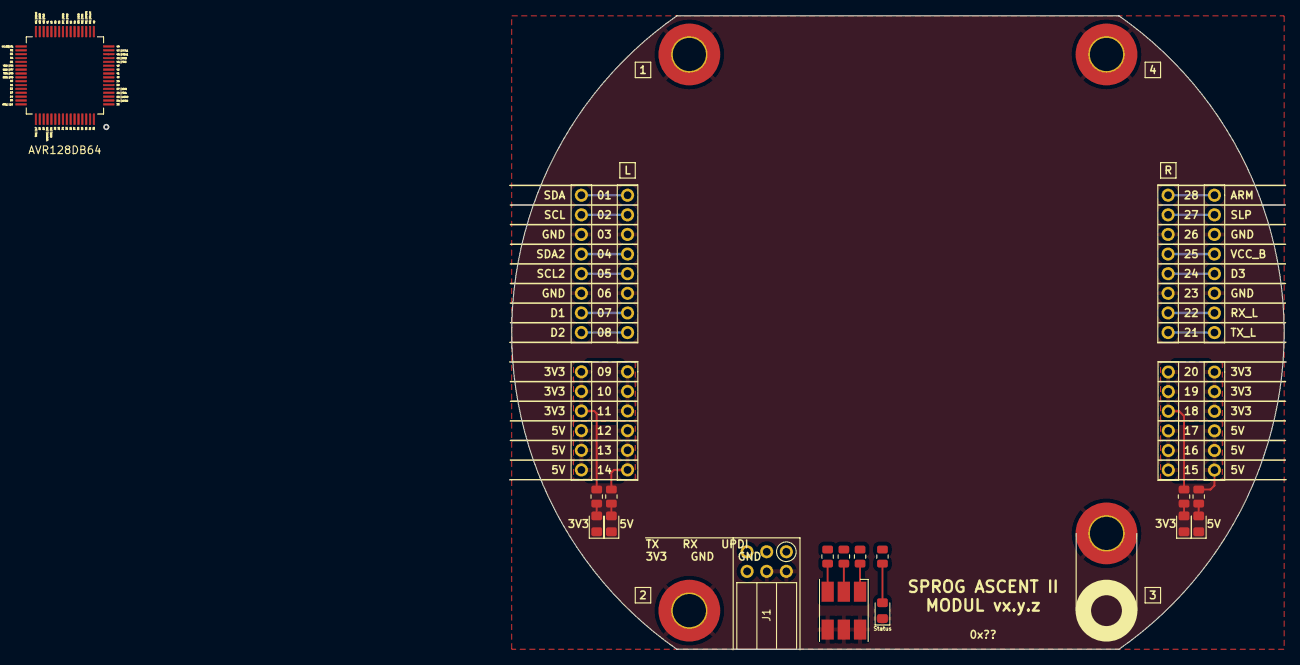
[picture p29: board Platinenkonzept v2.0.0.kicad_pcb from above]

Board: 2 copper layers, 100.0 x 82.0 mm, 27 parts (0 on the bottom side), 19 nets.

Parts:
D1, D1#2, D1#3, D1#4, D1#5: LED; LED_0805_2012Metric_Pad1.15x1.40mm_HandSolder
D2: CLS6B-FKW; LED_RGB_Cree-PLCC-6_6x5mm_P2.1mm
J1: Conn_02x03_Odd_Even; PinSocket_2x03_P2.54mm_Horizontal
JL1, JL3: Conn_01x08_Pin; PinSocket_1x08_P2.54mm_Vertical
JL2, JL4: Conn_01x06_Pin; PinSocket_1x06_P2.54mm_Vertical
JR1, JR3: Conn_01x08_Pin; PinSocket_1x08_P2.54mm_Vertical
JR2, JR4: Conn_01x06_Pin; PinSocket_1x06_P2.54mm_Vertical
M1, M2, M3, M4: Conn_01x01_Pin; m4hole
R1, R1#2, R1#3, R1#4, R1#5, R2, R3, R4: R; R_0805_2012Metric

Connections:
+3V3: J1.2, JL2.9 (Pin_1), JL2.10 (Pin_2), JL2.11 (Pin_3), JL4.9 (Pin_1), JL4.10 (Pin_2), JL4.11 (Pin_3), JR2.18 (Pin_3), JR2.19 (Pin_2), JR2.20 (Pin_1), JR4.18 (Pin_3), JR4.19 (Pin_2), JR4.20 (Pin_1), R1#4.1, R1#5.1
+5V: JL2.12 (Pin_4), JL2.13 (Pin_5), JL2.14 (Pin_6), JL4.12 (Pin_4), JL4.13 (Pin_5), JL4.14 (Pin_6), JR2.15 (Pin_6), JR2.16 (Pin_5), JR2.17 (Pin_4), JR4.15 (Pin_6), JR4.16 (Pin_5), JR4.17 (Pin_4), R1#2.1, R1#3.1
ARM: JR1.28 (Pin_1), JR3.28 (Pin_1)
D1: JL1.7, JL3.7
D2: JL1.8, JL3.8
D3: JR1.24 (Pin_5), JR3.24 (Pin_5)
GND: D1.1 (K), D1#2.1 (K), D1#3.1 (K), D1#4.1 (K), D1#5.1 (K), D2.4 (KB), D2.5 (KR), D2.6 (KR), J1.4, J1.6, JL1.3, JL1.6, JL3.3, JL3.6, JR1.23 (Pin_6), JR1.26 (Pin_3), JR3.23 (Pin_6), JR3.26 (Pin_3), M1.1, M2.1, M3.1, M4.1
unnamed: D1.2 (A), D1#2.2 (A), D1#3.2 (A), D1#4.2 (A), D1#5.2 (A), R1.2, R1#2.2, R1#3.2, R1#4.2, R1#5.2
unnamed: D2.3 (AB), R4.2
unnamed: D2.2 (AG), R3.2
unnamed: D2.1 (AR), R2.2
RX_L: JR1.22 (Pin_7), JR3.22 (Pin_7)
SCL: JL1.2, JL3.2
SCL2: JL1.5, JL3.5
SDA: JL1.1, JL3.1
SDA2: JL1.4, JL3.4
SLP: JR1.27 (Pin_2), JR3.27 (Pin_2)
TX_L: JR1.21 (Pin_8), JR3.21 (Pin_8)
VCC_B: JR1.25 (Pin_4), JR3.25 (Pin_4)

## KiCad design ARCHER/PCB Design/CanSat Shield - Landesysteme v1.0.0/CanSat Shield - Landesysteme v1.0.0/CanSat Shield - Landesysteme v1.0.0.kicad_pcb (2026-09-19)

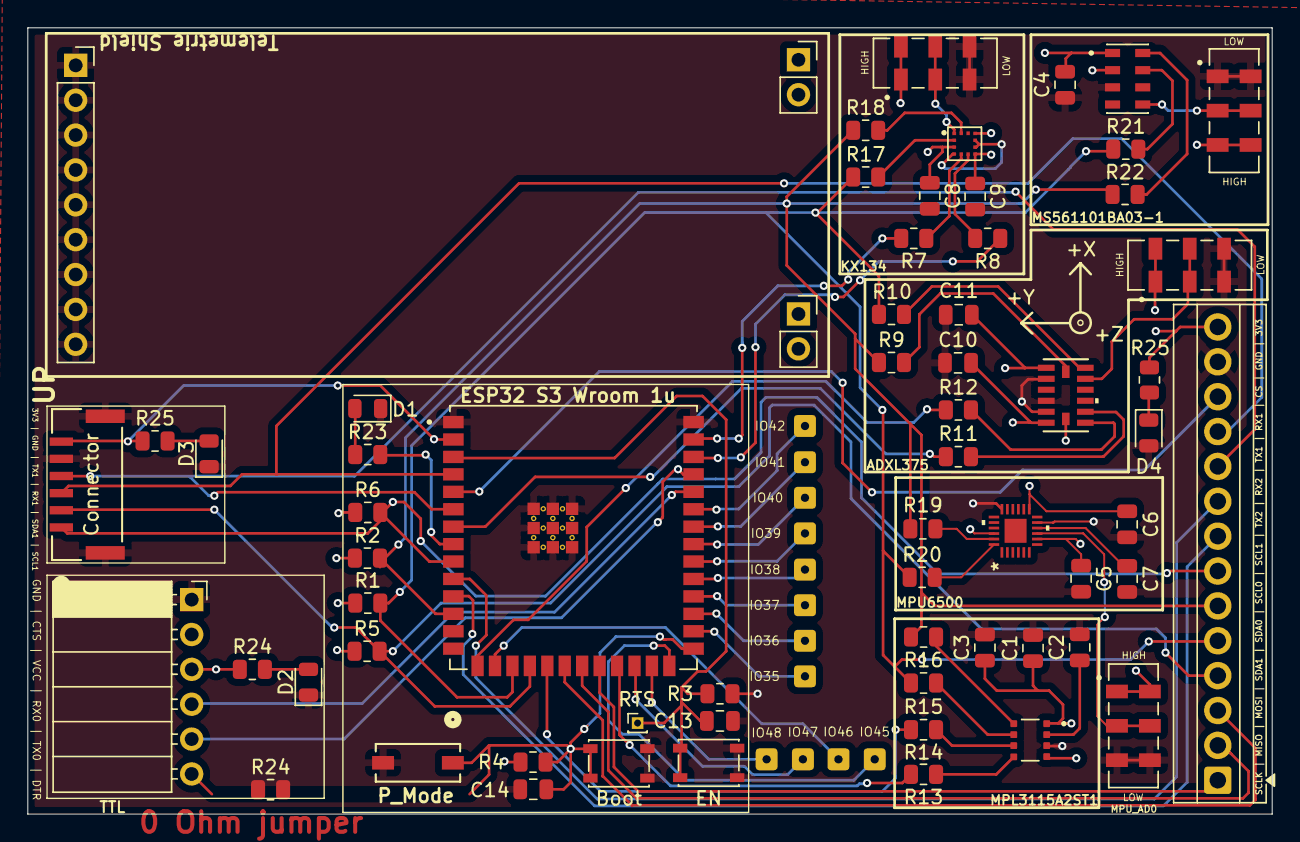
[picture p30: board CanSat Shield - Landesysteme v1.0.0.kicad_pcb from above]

Board: 2 copper layers, 90.7 x 57.3 mm, 75 parts (0 on the bottom side), 56 nets.

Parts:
ADXL: JS202011JAQN (Switch); SW_JS202011JCQN
ADXL1: LGA_CC-14-1_ADI-M
Boot: SW_SPST_PTS810
C1, C2, C4, C13, C14: 100 nF; C_0805_2012Metric
C3: 10 uF; C_0805_2012Metric
C5: 10 nF; C_0805_2012Metric
C6: 0,1 uF; C_0805_2012Metric
C7, C8, C9, C11: 0.1 uF; C_0805_2012Metric
C10: 1 uF; C_0805_2012Metric
Connector: Connector; CONN_SM06B-GHS-TB_JST
D1, D2, D3, D4: 2V; LED_0805_2012Metric
EN: Works as reset button; SW_SPST_PTS810
ESP32 S3 Wroom 1u: ESP32-S3-WROOM-1U; XCVR_ESP32-S3-WROOM-1U
HIGH: JS202011JAQN (Switch); SW_JS202011JCQN
HIGH#2: JS202011JAQN (Switch); SW_JS202011JCQN
IO35, IO36, IO37, IO38, IO39, IO40, IO41, IO42, IO45, IO46, IO47, IO48: Conn_01x01; SolderWire-0.1sqmm_1x01_D0.4mm_OD1mm
J1: TTL; PinSocket_1x06_P2.54mm_Horizontal
J4: Tele-GND; PinSocket_1x09_P2.54mm_Vertical
J5, J6: Conn_01x02_Socket; PinSocket_1x02_P2.54mm_Vertical
KX1: XDCR_KX003-1077
MPL3115A2ST1: PSON80P300X300X100-8N
MPU6500: QFN24_3X3X0P9_IVS-M
MS561101BA03-1: XDCR_MS561101BA03-50
R1, R2, R3, R4, R5, R6: 10k; R_0805_2012Metric
R7, R8, R9, R10, R11, R12, R13, R14, R15, R16, R17, R18, R19, R20, R21, R22: 0R; R_0805_2012Metric
R23, R24, R24#2, R25, R25#2: 56R; R_0805_2012Metric
SCLK | MISO | MOSI | SDA1 | SDA0 | SCL0 | SCL1 | TX2 | RX2 | TX1 | RX1 | CS | GND | 3V3: Screw_Terminal_01x14; TerminalBlock_Xinya_XY308-2.54-14P_1x14_P2.54mm_Horizontal
SW1(Slideswitch)1: GND if disengaged, IO0 if engaged; SW_CHS-01TA_NDC
SW2: JS202011JAQN (Switch); SW_JS202011JCQN

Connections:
+3V3: ADXL.1, ADXL.5, ADXL1.CS, ADXL1.VDD, ADXL1.VDD_IO, C1.1, C3.1, C4.VDD, C5.VDD_IO, C6.VDD, C8.VDD_IO, C9.VDD, C10.VDD, C11.VDD_IO, Connector.6, ESP32 S3 Wroom 1u.VDD, HIGH.1, HIGH.5, HIGH#2.1, HIGH#2.5, J1.3, KX1.VDD, KX1.VDD_IO, KX1.nCS, MPL3115A2ST1.VDD, MPL3115A2ST1.VDD_IO, MPU6500.VDD, MPU6500.VDDIO, MPU6500.nCS, MS561101BA03-1.PS, MS561101BA03-1.VDD, R1.1, R2.1, R3.1, R4.1, R5.1, R6.1, R24#2.1, R25.2, R25#2.1, SCLK | MISO | MOSI | SDA1 | SDA0 | SCL0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.14, SW2.3, SW2.7
AD0: HIGH#2.2, HIGH#2.6, MPU6500.AD0
ADDR_ADXL: ADXL.2, ADXL.6, ADXL1.ADDR_ADXL
ADDR_KX: HIGH.2, HIGH.6, KX1.ADDR_KX
CS: ESP32 S3 Wroom 1u.5 (CS), SCLK | MISO | MOSI | SDA1 | SDA0 | SCL0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.12
GND1: ADXL.3, ADXL.7, ADXL1.2 (GND), ADXL1.4 (GND), ADXL1.5 (GND), Boot.1, Boot.2, C1.2, C2.2, C3.2, C4.2, C5.2, C6.1, C7.2, C8.2, C9.2, C10.2, C11.1, C13.2, C14.2, Connector.5, Connector.7, Connector.8, D1.1 (K), D2.1 (K), D3.1 (K), D4.2 (A), EN.1, EN.2, ESP32 S3 Wroom 1u.1 (GND), ESP32 S3 Wroom 1u.40 (GND), ESP32 S3 Wroom 1u.41_1 (GND), ESP32 S3 Wroom 1u.41_2 (GND), ESP32 S3 Wroom 1u.41_3 (GND), ESP32 S3 Wroom 1u.41_4 (GND), ESP32 S3 Wroom 1u.41_5 (GND), ESP32 S3 Wroom 1u.41_6 (GND), ESP32 S3 Wroom 1u.41_7 (GND), ESP32 S3 Wroom 1u.41_8 (GND), ESP32 S3 Wroom 1u.41_9 (GND), HIGH.3, HIGH.7, HIGH#2.3, HIGH#2.7, J1.1, J4.1, J4.2, J4.3, J4.4, J4.5, J4.6, J4.7, J4.8, J4.9, KX1.8 (GND), KX1.9 (GND), KX1.TRIG, MPL3115A2ST1.3, MPU6500.11 (FSYNC), MPU6500.18 (GND), MS561101BA03-1.3 (GND), SCLK | MISO | MOSI | SDA1 | SDA0 | SCL0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.13, SW1(Slideswitch)1.2, SW2.1, SW2.5
INT1_ADXL: ESP32 S3 Wroom 1u.15 (IO3), R12.2
INT1_KX: ESP32 S3 Wroom 1u.39 (IO1), R7.2
INT1_MPL: ESP32 S3 Wroom 1u.19 (IO11), R14.2
INT2_ADXL: ESP32 S3 Wroom 1u.7 (IO7), R11.1
INT2_KX: ESP32 S3 Wroom 1u.38 (IO2), R8.2
INT2_MPL: ESP32 S3 Wroom 1u.23 (IO21), R13.2
IO0: Boot.1, Boot.2, C14.1, ESP32 S3 Wroom 1u.27 (IO0_(Programming)), J1.6, R4.2, SW1(Slideswitch)1.1
MISO: ESP32 S3 Wroom 1u.21 (MISO), SCLK | MISO | MOSI | SDA1 | SDA0 | SCL0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.2
MOSI: ESP32 S3 Wroom 1u.20 (MOSI), SCLK | MISO | MOSI | SDA1 | SDA0 | SCL0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.3
unnamed: ADXL1.8 (INT1), R12.1
unnamed: ADXL1.9 (INT2), R11.2
unnamed: ADXL1.14 (SCL/SCLK), R9.2
unnamed: ADXL1.13 (SDA/SDI/SDIO), R10.2
unnamed: D1.2 (A), R23.1
unnamed: D2.2 (A), R24#2.2
unnamed: C13.1, EN.1, EN.2, ESP32 S3 Wroom 1u.3 (EN), R3.2
unnamed: ESP32 S3 Wroom 1u.LED (IO15), R23.2
unnamed: ESP32 S3 Wroom 1u.28 (IO35), IO35.1
unnamed: ESP32 S3 Wroom 1u.29 (IO36), IO36.1
unnamed: ESP32 S3 Wroom 1u.30 (IO37), IO37.1
unnamed: ESP32 S3 Wroom 1u.31 (IO38), IO38.1
unnamed: ESP32 S3 Wroom 1u.32 (IO39), IO39.1
unnamed: ESP32 S3 Wroom 1u.33 (IO40), IO40.1
unnamed: ESP32 S3 Wroom 1u.34 (IO41), IO41.1
unnamed: ESP32 S3 Wroom 1u.35 (IO42), IO42.1
unnamed: ESP32 S3 Wroom 1u.26 (IO45), IO45.1
unnamed: ESP32 S3 Wroom 1u.16 (IO46), IO46.1
unnamed: ESP32 S3 Wroom 1u.24 (IO47), IO47.1
unnamed: ESP32 S3 Wroom 1u.25 (IO48), IO48.1
unnamed: KX1.5 (INT1), R7.1
unnamed: KX1.6 (INT2), R8.1
unnamed: KX1.12 (SCLK/SCL), R18.2
unnamed: KX1.2 (SDI/SDA), R17.2
unnamed: C7.1, MPU6500.10 (REGOUT)
unnamed: MPU6500.23 (SCL/SCLK), R19.1
unnamed: MPU6500.24 (SDA/SDI), R20.2
unnamed: MS561101BA03-1.8 (SCLK), R22.1
unnamed: MS561101BA03-1.7 (SDI/SDA), R21.2
unnamed: MS561101BA03-1.4 (~CSB), MS561101BA03-1.CBS, SW2.2, SW2.6
RX0: ESP32 S3 Wroom 1u.36 (RXD0), J1.4
RX1: Connector.3, ESP32 S3 Wroom 1u.4 (RX1), SCLK | MISO | MOSI | SDA1 | SDA0 | SCL0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.11
RX2: ESP32 S3 Wroom 1u.10 (RX2), SCLK | MISO | MOSI | SDA1 | SDA0 | SCL0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.9
SCL0: ESP32 S3 Wroom 1u.12 (SCL0), R2.2, R9.1, R16.1, R18.1, R19.2, R22.2, SCLK | MISO | MOSI | SDA1 | SDA0 | SCL0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.6
SCL1: Connector.1, ESP32 S3 Wroom 1u.9 (SCL1), R6.2, SCLK | MISO | MOSI | SDA1 | SDA0 | SCL0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.7
SCLK: ESP32 S3 Wroom 1u.22 (SCLK), SCLK | MISO | MOSI | SDA1 | SDA0 | SCL0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.1
SDA0: ESP32 S3 Wroom 1u.17 (SDA0), R1.2, R10.1, R15.1, R17.1, R20.1, R21.1, SCLK | MISO | MOSI | SDA1 | SDA0 | SCL0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.5
SDA1: Connector.2, ESP32 S3 Wroom 1u.18 (SDA1), R5.2, SCLK | MISO | MOSI | SDA1 | SDA0 | SCL0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.4
TX0: ESP32 S3 Wroom 1u.37 (TXD0), J1.5
TX1: Connector.4, ESP32 S3 Wroom 1u.6 (TX1), SCLK | MISO | MOSI | SDA1 | SDA0 | SCL0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.10
TX2: ESP32 S3 Wroom 1u.11 (TX2), SCLK | MISO | MOSI | SDA1 | SDA0 | SCL0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.8

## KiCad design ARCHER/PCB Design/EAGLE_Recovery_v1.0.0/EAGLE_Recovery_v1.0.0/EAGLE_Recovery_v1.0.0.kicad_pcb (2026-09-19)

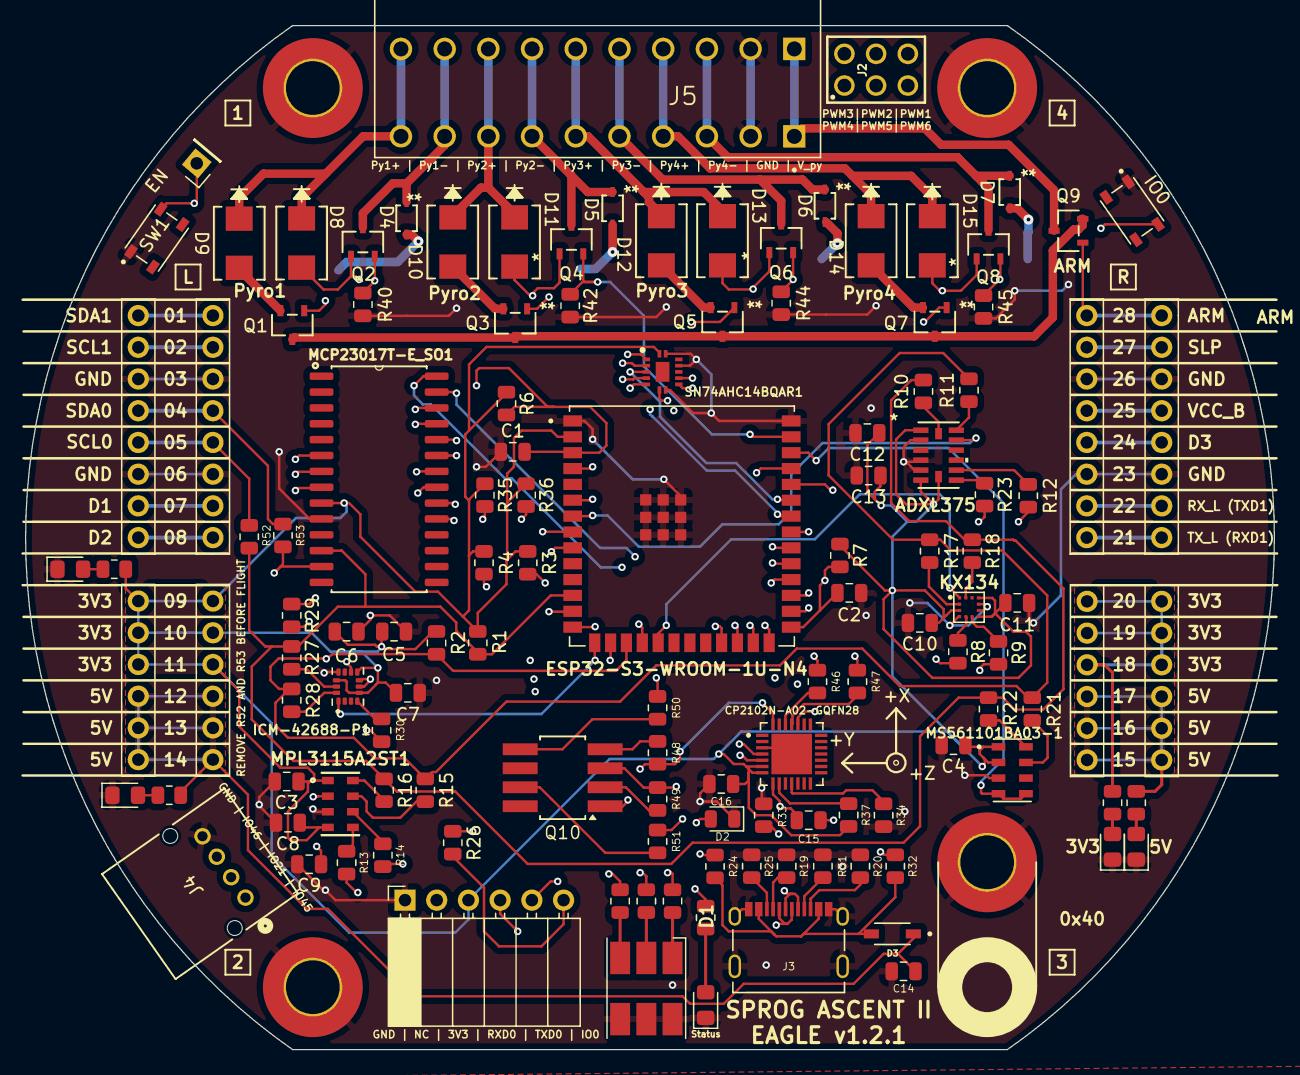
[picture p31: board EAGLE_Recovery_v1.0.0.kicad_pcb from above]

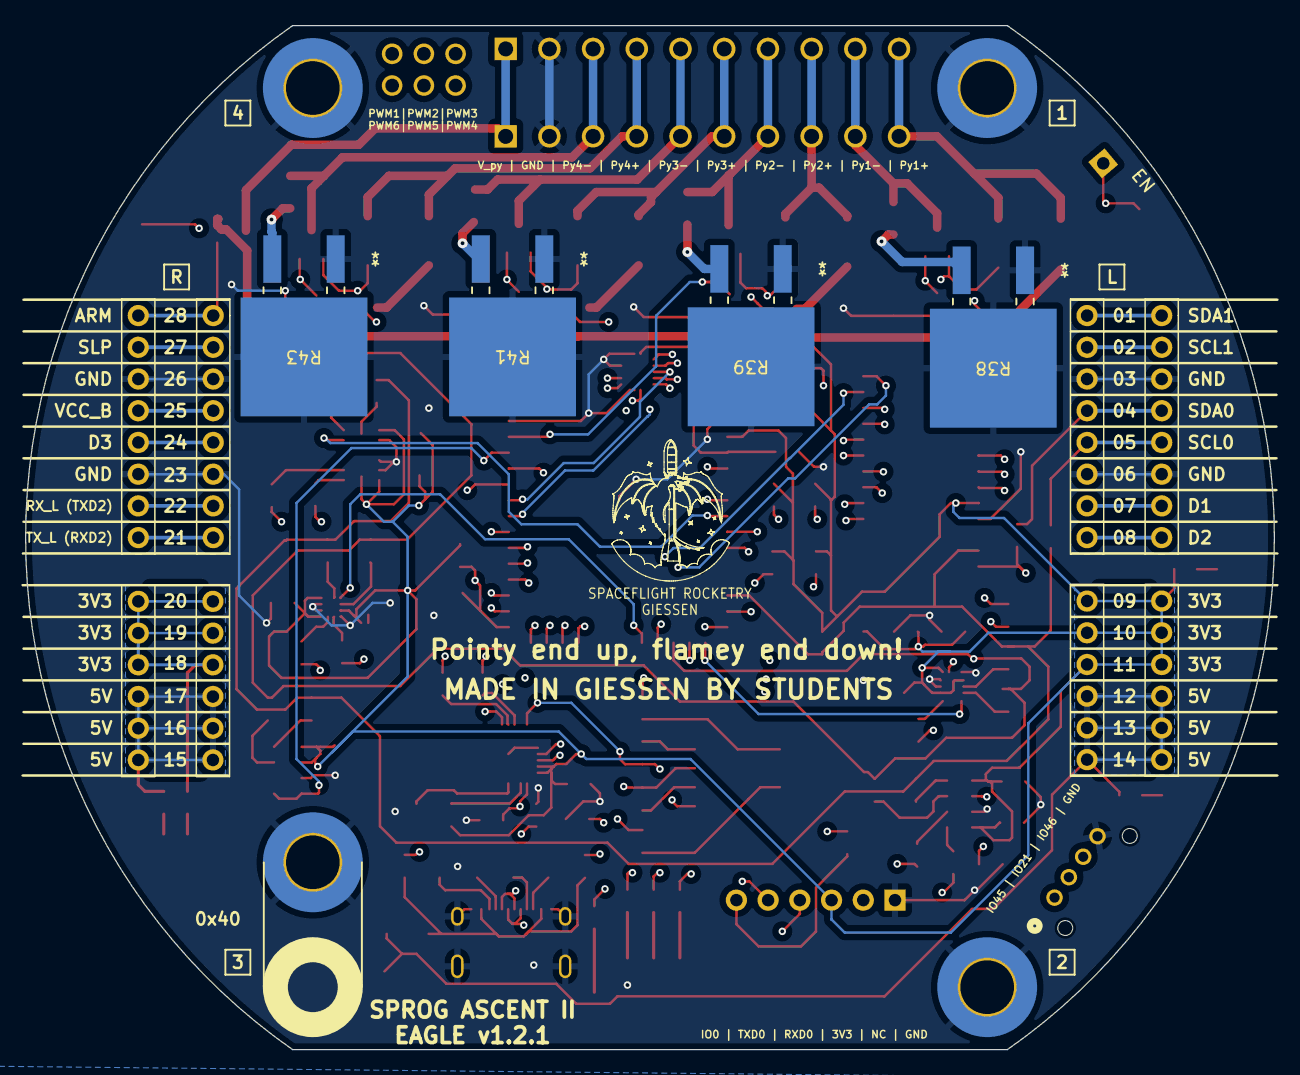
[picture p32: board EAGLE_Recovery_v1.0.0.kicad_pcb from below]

Board: 4 copper layers, 100.0 x 82.0 mm, 135 parts (4 on the bottom side), 115 nets.

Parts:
ADXL375: SPROG_ADXL375-M
C1, C2, C3, C4, C5, C7, C9: 100 nF; C_0805_2012Metric
C6: 2.2 uF; C_0805_2012Metric
C8, C14, C16: 10 uF; C_0805_2012Metric
C10, C11, C12: 0.1 uF; C_0805_2012Metric
C13, C15: 1 uF; C_0805_2012Metric
CP2102N-A02-GQFN28: CP2102N-A02-GQFN28; SPROG_CP2102N-A02-GQFN28
D1, D1#2, D1#3, D1#4, D1#5: LED; LED_0805_2012Metric_Pad1.15x1.40mm_HandSolder
D2: CLS6B-FKW; LED_RGB_Cree-PLCC-6_6x5mm_P2.1mm
D2#2: LED; LED_0805_2012Metric
D3: 1N5819HW-7-F; SPROG_1N5819HW-7-F
D4, D5, D6, D7: D_Zener_Small; SPROG_AQ4020_LTF
D8, D9, D10, D11, D12, D13, D14, D15: Shottkey; SPROG_DO214AA_MBRS_VIS
EN: RTS (EN); PinHeader_1x01_P2.54mm_Vertical
ESP32-S3-WROOM-1U-N4: ESP32-S3-WROOM-1U-N4; SPROG_ESP32-S3-WROOM-1U-N4
ICM-42688-P1: ICM-42688-P; SPROG_ICM-42688-P
IO0: Prog.; SPROG_SW_PTS810_SJM
J2: 6130XX21121_61300621121; SPROG_61300621121
J3: GSB1C411101DS1HR; SPROG_GSB1C411101DS1HR
J4: Screw_Terminal_01x04; SPROG_CONN4_S04B-PASK_JST
J5: TBLH10-350-10BK; SPROG_TBLH10-350-10BK
J6: TTL; PinSocket_1x06_P2.54mm_Horizontal
JL1, JL3: Conn_01x08_Pin; PinSocket_1x08_P2.54mm_Vertical
JL2, JL4: Conn_01x06_Pin; PinSocket_1x06_P2.54mm_Vertical
JR1, JR3: Conn_01x08_Pin; PinSocket_1x08_P2.54mm_Vertical
JR2, JR4: Conn_01x06_Pin; PinSocket_1x06_P2.54mm_Vertical
KX134: SPROG_KX134-1211
M1, M2, M3, M4: Conn_01x01_Pin; m4hole
MCP23017T-E_SO1: MCP23017T-E_SO; SPROG_MCP23017T-E_SO
MPL3115A2ST1: SPROG_MPL3115A2
MS561101BA03-1: SPROG_MS561101BA03-50
Q1, Q2, Q3, Q4, Q5, Q6, Q7, Q8, Q9: PMV37ENEAR; SPROG_SOT23_PMV37_NEX
Q10: NPN; Zetex_SM8
R1, R1#2, R1#3, R1#5, R1#6, R2#2, R3, R4#2: R; R_0805_2012Metric
R1#4, R2, R3#2, R4, R6, R7, R34, R35, R36, R48, R49: 10k; R_0805_2012Metric
R8, R9, R10, R11, R12, R13, R14, R15, R16, R17, R18, R21, R22, R23, R27, R28, R29, R30, R46, R47, R50, R51, R52, R53: 0R; R_0805_2012Metric
R19, R20, R31: 5R1; R_0805_2012Metric
R24: 56R; R_0805_2012Metric
R25: 50R; R_0805_2012Metric
R26: OR; R_0805_2012Metric
R32: 22k1; R_0805_2012Metric
R33: 47k5; R_0805_2012Metric
R37: 1k; R_0805_2012Metric
R38, R39, R43: 1R5; SPROG_RES_PWR263S-20-1R50J
R40, R42, R44, R45: 300k; R_0805_2012Metric
R41: 5R1; SPROG_RES_PWR263S-20-1R50J
SN74AHC14BQAR1: SN74AHC14BQAR; SPROG_SN74AHC14BQAR
SW1: EN; SPROG_SW_PTS810_SJM

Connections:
+3V3: ADXL375.1 (IO_VDD), ADXL375.6 (VDD), ADXL375.7 (CS), C3.1, C4.1, C5.1, C6.1, C7.1, C8.1, C10.1, C11.1, C12.2, C13.1, C16.1, CP2102N-A02-GQFN28.6 (VDD), CP2102N-A02-GQFN28.7 (VREGIN), ESP32-S3-WROOM-1U-N4.2 (3V3), ICM-42688-P1.5 (VDDIO), ICM-42688-P1.8 (VDD), ICM-42688-P1.12 (AP_CS), J6.3 (3V3), JL2.9 (Pin_1), JL2.10 (Pin_2), JL2.11 (Pin_3), JL4.9 (Pin_1), JL4.10 (Pin_2), JL4.11 (Pin_3), JR2.18 (Pin_3), JR2.19 (Pin_2), JR2.20 (Pin_1), JR4.18 (Pin_3), JR4.19 (Pin_2), JR4.20 (Pin_1), KX134.3 (IO_VDD), KX134.7 (VDD), KX134.10 (nCS), MCP23017T-E_SO1.9 (VDD), MPL3115A2ST1.1 (V_DD), MPL3115A2ST1.4 (V_DDIO), MS561101BA03-1.1 (VDD), MS561101BA03-1.2 (PS), R1#2.1, R1#4.1, R1#6.1, R2.1, R3#2.1, R4.1, R6.1, R7.1, R35.1, R36.1, R37.1, SN74AHC14BQAR1.14 (VCC)
+5V: C14.1, D3.C, JL2.12 (Pin_4), JL2.13 (Pin_5), JL2.14 (Pin_6), JL4.12 (Pin_4), JL4.13 (Pin_5), JL4.14 (Pin_6), JR2.15 (Pin_6), JR2.16 (Pin_5), JR2.17 (Pin_4), JR4.15 (Pin_6), JR4.16 (Pin_5), JR4.17 (Pin_4), R1.1, R1#5.1
ADDR_ADXL: ADXL375.12 (SDO/ADDR), ESP32-S3-WROOM-1U-N4.7 (IO7)
ADDR_KX: ESP32-S3-WROOM-1U-N4.19 (IO11), KX134.1 (SDO/ADDR)
ADO_ICM: ESP32-S3-WROOM-1U-N4.15 (IO3), ICM-42688-P1.1 (AP_SDO/AP_AD0)
ARM: JR1.28 (Pin_1), JR3.28 (Pin_1), Q9.1 (G)
CSB: ESP32-S3-WROOM-1U-N4.38 (IO2), MS561101BA03-1.4 (~CSB), MS561101BA03-1.5 (~CSB)
D1: JL1.7, JL3.7
D2: JL1.8, JL3.8
D3: JR1.24 (Pin_5), JR3.24 (Pin_5)
D+: CP2102N-A02-GQFN28.4 (D+), ESP32-S3-WROOM-1U-N4.14 (IO20/USB_D+), J3.A6 (D1+), J3.B6 (D2+)
D-: CP2102N-A02-GQFN28.5 (D-), ESP32-S3-WROOM-1U-N4.13 (IO19/USB_D-), J3.A7 (D1-), J3.B7 (D2-)
DTR: CP2102N-A02-GQFN28.28 (DTR), Q10.1 (C), R48.2
EN: C1.2, EN.1, ESP32-S3-WROOM-1U-N4.3 (EN), R6.2, R50.2, SW1.2
GND: ADXL375.2 (GND), ADXL375.4 (GND), ADXL375.5 (GND), C1.1, C2.2, C3.2, C4.2, C5.2, C6.2, C7.2, C8.2, C9.2, C10.2, C11.2, C12.1, C13.2, C14.2, C15.2, C16.2, CP2102N-A02-GQFN28.3 (GND), CP2102N-A02-GQFN28.29 (GND__1), D1.1 (K), D1#2.1 (K), D1#3.1 (K), D1#4.1 (K), D1#5.1 (K), D2.4 (KB), D2.5 (KR), D2.6 (KR), D2#2.1 (K), ESP32-S3-WROOM-1U-N4.1 (GND), ESP32-S3-WROOM-1U-N4.40 (GND), ESP32-S3-WROOM-1U-N4.41_1 (GND), ESP32-S3-WROOM-1U-N4.41_2 (GND), ESP32-S3-WROOM-1U-N4.41_3 (GND), ESP32-S3-WROOM-1U-N4.41_4 (GND), ESP32-S3-WROOM-1U-N4.41_5 (GND), ESP32-S3-WROOM-1U-N4.41_6 (GND), ESP32-S3-WROOM-1U-N4.41_7 (GND), ESP32-S3-WROOM-1U-N4.41_8 (GND), ESP32-S3-WROOM-1U-N4.41_9 (GND), ICM-42688-P1.6 (GND), ICM-42688-P1.7 (RESV_7), ICM-42688-P1.11 (RESV_11), IO0.1 (A), J3.A1B12 (GND_A), J3.B1A12 (GND_B), J3.SH1 (SHIELD), J3.SH2 (SHIELD__1), J3.SH3 (SHIELD__2), J3.SH4 (SHIELD__3), J4.4, J5.2_A (2), J5.2_B (2__1), J6.1 (GND), JL1.3, JL1.6, JL3.3, JL3.6, JR1.23 (Pin_6), JR1.26 (Pin_3), JR3.23 (Pin_6), JR3.26 (Pin_3), KX134.4 (TRIG), KX134.8 (GND), KX134.9 (GND), M1.1, M2.1, M3.1, M4.1, MCP23017T-E_SO1.10 (VSS), MPL3115A2ST1.3 (GND), MS561101BA03-1.3 (GND), R19.2, R20.1, R25.1, R31.1, R33.2, R34.1, R38.1, R38.2, R39.1, R39.2, R40.2, R41.1, R41.2, R42.2, R43.1, R43.2, R44.2, R45.2, SN74AHC14BQAR1.7 (GND), SN74AHC14BQAR1.11 (5A), SN74AHC14BQAR1.13 (6A), SW1.1
INT1_ADXL: MCP23017T-E_SO1.24 (GPA3), R23.2
INT1_ICM: MCP23017T-E_SO1.25 (GPA4), R30.2
INT1_KX: MCP23017T-E_SO1.27 (GPA6), R8.2
INT1_MPL: MCP23017T-E_SO1.21 (GPA0), R14.2
INT2_ADXL: MCP23017T-E_SO1.23 (GPA2), R12.1
INT2_ICM: MCP23017T-E_SO1.26 (GPA5), R29.1
INT2_KX: MCP23017T-E_SO1.28 (GPA7), R9.2
INT2_MPL: MCP23017T-E_SO1.22 (GPA1), R13.2
IO0: C2.1, ESP32-S3-WROOM-1U-N4.27 (IO0_(P)), IO0.2 (B), R7.2, R26.2, R51.2
IO1/Cont.: ESP32-S3-WROOM-1U-N4.39 (IO1/Cont.), Q2.2 (S), Q4.2 (S), Q6.2 (S), Q8.2 (S), R40.1, R42.1, R44.1, R45.1
IO21: ESP32-S3-WROOM-1U-N4.23 (IO21), J4.2
IO41: ESP32-S3-WROOM-1U-N4.34 (IO41/Pyro1), Q1.1 (G), SN74AHC14BQAR1.1 (1A)
IO42: ESP32-S3-WROOM-1U-N4.35 (IO42/Pyro2), Q3.1 (G), SN74AHC14BQAR1.3 (2A)
IO45: ESP32-S3-WROOM-1U-N4.26 (IO45), J4.1
IO46/Conf.: ESP32-S3-WROOM-1U-N4.16 (IO46/Conf.), J4.3
IO47: ESP32-S3-WROOM-1U-N4.24 (IO47/Pyro3), Q5.1 (G), SN74AHC14BQAR1.5 (3A)
IO48: ESP32-S3-WROOM-1U-N4.25 (IO48/Pyro4), Q7.1 (G), SN74AHC14BQAR1.9 (4A)
LED B: MCP23017T-E_SO1.8 (GPB7), R4#2.1
LED G: MCP23017T-E_SO1.7 (GPB6), R3.1
LED R: MCP23017T-E_SO1.6 (GPB5), R2#2.1
unnamed: ADXL375.8 (INT1), R23.1
unnamed: ADXL375.9 (INT2), R12.2
unnamed: ADXL375.14 (SCL/SCLK), R10.2
unnamed: ADXL375.13 (SDA/SDI/SDIO), R11.2
unnamed: CP2102N-A02-GQFN28.25 (RXD), R47.1
unnamed: CP2102N-A02-GQFN28.26 (TXD), R46.1
unnamed: C15.1, CP2102N-A02-GQFN28.8 (VBUS), R32.1, R33.1
unnamed: CP2102N-A02-GQFN28.9 (~RST), R37.2
unnamed: CP2102N-A02-GQFN28.11 (~SUSPEND), R34.2
unnamed: D1.2 (A), D1#2.2 (A), D1#3.2 (A), D1#4.2 (A), D1#5.2 (A), R1.2, R1#2.2, R1#3.2, R1#5.2, R1#6.2
unnamed: D2#2.2 (A), R24.2
unnamed: D2.3 (AB), R4#2.2
unnamed: D2.2 (AG), R3.2
unnamed: D2.1 (AR), R2#2.2
unnamed: D4.2 (A), R38.3
unnamed: D5.2 (A), R39.3
unnamed: D6.2 (A), R41.3
unnamed: D7.2 (A), R43.3
unnamed: D9.2 (A), Q1.2 (S)
unnamed: D10.2 (A), Q3.2 (S)
unnamed: D12.2 (A), Q5.2 (S)
unnamed: D14.2 (A), Q7.2 (S)
unnamed: ESP32-S3-WROOM-1U-N4.8 (IO15/LED1), R1#3.1
unnamed: ESP32-S3-WROOM-1U-N4.28 (IO35/PWM1), J2.6
unnamed: ESP32-S3-WROOM-1U-N4.29 (IO36/PWM2), J2.4
unnamed: ESP32-S3-WROOM-1U-N4.30 (IO37/PWM3), J2.2
unnamed: ESP32-S3-WROOM-1U-N4.31 (IO38/PWM4), J2.1
unnamed: ESP32-S3-WROOM-1U-N4.32 (IO39/PWM5), J2.3
unnamed: ESP32-S3-WROOM-1U-N4.33 (IO40/PWM6), J2.5
unnamed: ICM-42688-P1.13 (AP_SCL/AP_SCLK), R27.2
unnamed: ICM-42688-P1.14 (AP_SDA/AP_SDIO/AP_SDI), R28.1
unnamed: ICM-42688-P1.4 (INT1/INT), R30.1
unnamed: ICM-42688-P1.9 (INT2/FSYNC/CLKIN), R29.2
unnamed: J3.A5 (CC1), R19.1
unnamed: J3.B5 (CC2), R20.2
unnamed: J3.A8 (SBU1), R31.2
unnamed: J3.B8 (SBU2), R25.2
unnamed: J6.6 (IO0), R26.1
unnamed: KX134.5 (INT1), R8.1
unnamed: KX134.6 (INT2), R9.1
unnamed: KX134.12 (SCLK/SCL), R18.2
unnamed: KX134.2 (SDI/SDA), R17.2
unnamed: MCP23017T-E_SO1.20 (INTA), R36.2
unnamed: MCP23017T-E_SO1.19 (INTB), R35.2
unnamed: C9.1, MPL3115A2ST1.2 (CAP)
unnamed: MPL3115A2ST1.6 (INT1), R14.1
unnamed: MPL3115A2ST1.5 (INT2), R13.1
unnamed: MPL3115A2ST1.8 (SCL), R16.2
unnamed: MPL3115A2ST1.7 (SDL), R15.2
unnamed: MS561101BA03-1.8 (SCLK), R22.1
unnamed: MS561101BA03-1.7 (SDI/SDA), R21.2
unnamed: Q10.4, R48.1
unnamed: Q10.5, Q10.6, R50.1
unnamed: Q10.2 (B), R49.1
unnamed: Q10.7, Q10.8, R51.1
Py1+: D8.1 (K), D9.1 (K), J5.10_A (10), J5.10_B (10__1)
Py1-: D4.1 (K), J5.9_A (9), J5.9_B (9__1), Q2.3 (D)
Py2+: D10.1 (K), D11.1 (K), J5.8_A (8), J5.8_B (8__1)
Py2-: D5.1 (K), J5.7_A (7), J5.7_B (7__1), Q4.3 (D)
Py3+: D12.1 (K), D13.1 (K), J5.6_A (6), J5.6_B (6__1)
Py3-: D6.1 (K), J5.5_A (5), J5.5_B (5__1), Q6.3 (D)
Py4+: D14.1 (K), D15.1 (K), J5.4_A (4), J5.4_B (4__1)
Py4-: D7.1 (K), J5.3_A (3), J5.3_B (3__1), Q8.3 (D)
Pyro1 (IO41): D8.2 (A), Q2.1 (G), SN74AHC14BQAR1.2 (1Y)
Pyro2 (IO42): D11.2 (A), Q4.1 (G), SN74AHC14BQAR1.4 (2Y)
Pyro3 (IO47): D13.2 (A), Q6.1 (G), SN74AHC14BQAR1.6 (3Y)
Pyro4 (IO48): D15.2 (A), Q8.1 (G), SN74AHC14BQAR1.8 (4Y)
RTS: CP2102N-A02-GQFN28.24 (RTS), Q10.3 (E), R49.2
RXD0: ESP32-S3-WROOM-1U-N4.36 (IO44/RXD0), J6.4 (RXD0), R47.2
RXD1: ESP32-S3-WROOM-1U-N4.4 (IO4/RXD1), JR1.21 (Pin_8), JR3.21 (Pin_8)
SCL0: ESP32-S3-WROOM-1U-N4.12 (IO8/SCL0), JL1.5, JL3.5, MCP23017T-E_SO1.12 (SCK), R1#4.2, R10.1, R16.1, R18.1, R22.2, R27.1, R52.1, R52.2
SCL1: ESP32-S3-WROOM-1U-N4.9 (IO16/SCL1), JL1.2, JL3.2, R4.2
SDA0: ESP32-S3-WROOM-1U-N4.17 (IO9/SDA0), JL1.4, JL3.4, MCP23017T-E_SO1.13 (SDA), R2.2, R11.1, R15.1, R17.1, R21.1, R28.2, R53.1, R53.2
SDA1: ESP32-S3-WROOM-1U-N4.18 (IO10/SDA1), JL1.1, JL3.1, R3#2.2
SLP: JR1.27 (Pin_2), JR3.27 (Pin_2)
TXD0: ESP32-S3-WROOM-1U-N4.37 (IO43/TXD0), J6.5 (TXD0), R46.2
TXD1: ESP32-S3-WROOM-1U-N4.6 (IO6/TXD1), JR1.22 (Pin_7), JR3.22 (Pin_7)
VBUS: D3.A, J3.A4B9 (VBUS_A), J3.B4A9 (VBUS_B), R24.1, R32.2
VCC_B: JR1.25 (Pin_4), JR3.25 (Pin_4)
V_py: J5.1_A (1), J5.1_B (1__1), Q1.3 (D), Q3.3 (D), Q5.3 (D), Q7.3 (D), Q9.2 (S), Q9.3 (D)

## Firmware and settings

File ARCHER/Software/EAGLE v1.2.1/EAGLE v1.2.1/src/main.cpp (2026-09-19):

#include <Arduino.h>
#include <HardwareSerial.h>
#include <stdio.h>
#include <Wire.h>
#include <Adafruit_I2CDevice.h>
#include <Adafruit_Sensor.h>
#include <Adafruit_ADXL375.h>
#include <Adafruit_MCP23X17.h>
#include <MS5611.h>
#include <Adafruit_MPL3115A2.h>
#include "ICM42688.h"
#include <SparkFun_KX13X.h>
#include <Math.h>

//The following states are possible:
// 0000 0000 (0) [0x00]: Pad Idle
// 0000 0001 (1) [0x01]: Main deploy setpoint set
// 0000 0010 (2) [0x02]: Continuity positive
// 0000 0011 (3) [0x03]: Armed
// 0000 0100 (4) [0x04]: Liftoff detected
// 0000 0101 (5) [0x05]: Booster Burnout/Coasting
// 0000 0110 (6) [0x06]: Apogee detected
// 0000 0111 (7) [0x07]: Pyro 1 signal sent (drogue)
// 0000 1000 (8) [0x08]: Pyro2 signal sent (drogue)
// 0000 1001 (9) [0x09]: Drogue deplyoment detected
// 0000 1010 (10) [0x0A]: Pyro3 signal sent (main
// 0000 1011 (11) [0x0B]: Pryo4 signal sent (main)
// 0000 1100 (12) [0x0C]: Main deployment detected
// 0000 1101 (13) [0x0D]: Landed
// 0000 1110 (14) [0x0E]: ABORT - Failed to initialize
// 0000 1111 (15) [0x0F]: ABORT - No continuity

//The following commands are possible:
// a: 50 m
// b: 100 m
// c: 150 m
// d: 200 m
// f: arming
// g: arming zurücknehmen 
// q: drogue ejection 
// r: main ejection
// called in ReceiveFunc() function

//Code includes test setup and flight code by using following defines to enable/disable code: "TEST" "FLIGHT" 
#define FLIGHT
#define TIMERSETPOINT 0 //to be added with timer set point from simulations (in ms)

TwoWire MASTER = TwoWire(0);
TwoWire SLAVE = TwoWire(1);
Adafruit_I2CDevice i2c_dev = Adafruit_I2CDevice(0x10);
Adafruit_MCP23X17 mcp;
Adafruit_ADXL375 accel = Adafruit_ADXL375(12345);
MS5611 MS(0x77);
Adafruit_MPL3115A2 baro;
ICM42688 IMU(Wire, 0x68);
SparkFun_KX134 kxAccel; //Declares type of KX13x Accelerometer used
HardwareSerial Serial1(1); // Für die Ausgabe am Serial Monitor
HardwareSerial Serial2(2); // 1 = USB Serial, wir können also 2 oder 3 wählen

outputData kxData; //Struct for accelerometer's data

char arr_tel[2]; //global status array
char status = 0; //global status byte
char cmd = 0; //global command byte
float mainSetPoint = 0; 
float p0 = 0; //in Pa
float alt = 0;
const int contPIN = 1;
unsigned long start = 0;


int SensorInit() {
  #ifdef FLIGHT

    int initSensors = 0;

    if(mcp.begin_I2C())
    initSensors++;
    delay(100);

    if(accel.begin())
    initSensors++;
    delay(100);

    if(baro.begin());
    initSensors++;
    delay(100);

    if(MS.begin())
    initSensors++;
    delay(100);

    if(IMU.begin())
    initSensors++;
    delay(100);

    if(kxAccel.begin())
    initSensors++;
    delay(100);

    if(initSensors == 6)
      return 1;
    else
      return 0;
  #endif

  #ifdef TEST

    //Initialize MCP (GPIO extender)
    if (!mcp.begin()) 
      Serial.println("MCP23017 init failed!");
    else
      Serial.println("MCP23017 initialized.");
    delay(100);

    //initalize ADXL375 (Accelerometer)
    if(!accel.begin())
      Serial.println("AXL375 init failed!");
    else
      Serial.println("ADXL375 initialized.");
    delay(100);

    //Initialize MPL
    if(!baro.begin()) 
      Serial.println("MPL init failed!");
    else
     Serial.println("MPL initialized.");
    delay(100);

    //Initialize MS5611
    if(!MS.begin())
      Serial.println("MS5611 init failed!");
    else
      Serial.println("MS4511 initialized.");
    delay(100);

    //Initialize ICM42688
    if(!IMU.begin())
      Serial.println("ICMinit failed!");
    else
      Serial.println("ICM42688 initizialized");
    delay(100);

    //Initialize KX134
    if (!kxAccel.begin())
      Serial.println("KX134 init failed!");
    else
      Serial.println("KX134 initializied");
    delay(100);

    return 1;

  #endif
}

void RequestFunc() {
  arr_tel[0] = 0; //to be used for LED

  arr_tel[1] = status;
  for(int i = 0; i < 2; i++)
    SLAVE.write(arr_tel[i]);
}

void cmdFunc() {
  for(int i = 0; i>1; i++)
    char cmd = SLAVE.read();
}

void setup() {
  bool sensorInit = 0; //boolean to show if all sensors have been initialized
  unsigned long timerSetPoint = TIMERSETPOINT; //in ms 
  int contThresh = 2480; //equivalent to approx. 2V -> ideally it should be 3V3

  MASTER.setPins(9, 8);
  MASTER.begin();

  SLAVE.setPins(10, 16);
  SLAVE.begin(0x40);
  SLAVE.onRequest(RequestFunc);

  Serial1.begin(9600, SERIAL_8N1, 44, 43);
  Serial2.begin(9600, SERIAL_8N1, 4, 5);

  sensorInit = SensorInit();

  

  pinMode(contPIN, INPUT);
  pinMode(41, OUTPUT);
  pinMode(42, OUTPUT);

  float press[20] = {0};

  for(int i = 0; i<10; i++) { //read pressure sensors 10 times
    MS.read();

    press[i] = MS.getPressurePascal();

    press[i+10] = baro.getPressure()/100; //convert from hPa to Pa

    int p0 = (press[i] + press[i+10])/10; //get avg of first 10 measurement for ground level pressure
  }



  #ifdef TEST

    for(int i = 0; i>10; i++) {
      status = 0x0E;
  
      sensorInit = SensorInit(); //try to reinitialize sensors -> might want to be deleted because if there is issues we should investigate

      //Run I2C scanner
      byte error, address;
      int nDevices;

      Serial1.println("Scanning...");

      nDevices = 0;
      for(address = 1; address < 127; address++ )
      {
        // The i2c_scanner uses the return value of
        // the Write.endTransmisstion to see if
        // a device did acknowledge to the address.
        MASTER.beginTransmission(address);
        error = MASTER.endTransmission();

        if (error == 0)
        {
        Serial1.print("I2C device found at address 0x");
          if (address<16)
            Serial1.print("0");
          Serial1.print(address,HEX);
          Serial1.println("  !");

          nDevices++;
        }
        else if (error==4)
        {
          Serial1.print("Unknown error at address 0x");
          if (address<16)
            Serial1.print("0");
          Serial1.println(address,HEX);
        }
      }
      if (nDevices == 0)
        Serial1.println("No I2C devices found\n");
      else
        Serial1.println("done\n");

      delay(5000);           // wait 5 seconds for next scan
    }

  #endif

  #ifdef FLIGHT

    while(sensorInit == 0) {  //stay in loop until every sensor is initialized
      status = 0x0E;
  
      sensorInit = SensorInit(); //try to reinitialize sensors -> might want to be deleted because if there is issues we should investigate

    //Run I2C scanner
      byte error, address;
      int nDevices;

      Serial0.println("Scanning...");

      nDevices = 0;
      for(address = 1; address < 127; address++ )
      {
        // The i2c_scanner uses the return value of
        // the Write.endTransmisstion to see if
        // a device did acknowledge to the address.
        MASTER.beginTransmission(address);
        error = MASTER.endTransmission();

        if (error == 0)
        {
        Serial1.print("I2C device found at address 0x");
          if (address<16)
            Serial1.print("0");
          Serial1.print(address,HEX);
          Serial1.println("  !");

          nDevices++;
        }
        else if (error==4)
        {
          Serial1.print("Unknown error at address 0x");
          if (address<16)
            Serial1.print("0");
          Serial1.println(address,HEX);
        }
      }
      if (nDevices == 0)
        Serial1.println("No I2C devices found\n");
      else
        Serial1.println("done\n");

      delay(5000);           // wait 5 seconds for next scan
    }

   while(status < 0x01) { //should only trigger if main set point has not already been set
      SLAVE.onReceive(cmdFunc);
      switch(cmd) {
        case 'a': mainSetPoint = 50; break; 
        case 'b': mainSetPoint = 100; break; 
        case 'c': mainSetPoint = 150; break; //not necessary but fuck it, redundant code
        case 'd': mainSetPoint = 200; break;
        default: mainSetPoint == 150; break;
      }
      if(mainSetPoint == 50 || mainSetPoint == 100 || mainSetPoint == 150 || mainSetPoint == 200) {
        status = 0x01;
      }
    }
  #endif
}

void Pre_Flight_Loop () {
  while(1) {
    SLAVE.onRequest(RequestFunc);

    float alt2 = 0; //moving avg variable
    float contThresh = 2480; //should be approx. 2V on 3V3 system
    float velX = 0;
    float velY = 0;
    float velZ = 0;
    float velZ_abs = 0;
    float vel = 0;
    float mpl_alt = 0;
    float ms_alt = 0;
    float sens_arr[3] = {0}; //Data packet received from sensorics -> format: arr[0] = GNSS altitude; arr[1] = GNSS vel; arr[2] = RotZ
    float raw_data[36] = {0}; //Data full of raw data
    float data[20] = {0}; //Data to be sent to sensorics for logging
    float conv[10] = {0}; //To copy into for processing of data
    float alt1[20] = {0};
    
  

    float contData = analogRead(contPIN);
    while(contData < contThresh) {  //stays in loop until continuity is detected
      status = 0x0F; 
      contData = analogRead(contPIN);
    }
    
    status = 0x02;

    SLAVE.onReceive(cmdFunc);

    if(cmd = 'f' && status == 0x02)
      status = 0x03; //confirms "armed" status

    for(int k=0; k<10; k++) { //iterate over 10 altitude points
      

    //Gather data
      unsigned long t2 = millis(); //get time before each sampling


      while(Serial2.available()) { //read three floats at a time
        for(int i=0; i<2; i++) {
          sens_arr[i] = Serial2.read();
          raw_data[i+12]; //append received data to raw data array
        }
      }

      sensors_event_t event; //Read ADXL375
      accel.getEvent(&event);
      raw_data[0] = event.acceleration.x;
      raw_data[1] = event.acceleration.y;
      raw_data[2] = event.acceleration.z;

      kxAccel.getAccelData(&kxData); //Read KX134
      raw_data[3] = kxData.xData;
      raw_data[4] = kxData.yData;
      raw_data[5] = kxData.zData;
      
      IMU.getAGT(); //Read ICM
      raw_data[6] = IMU.accX();
      raw_data[7] = IMU.accY();
      raw_data[8] = IMU.accZ();
      raw_data[9] = IMU.gyrZ(); //z-Axis should be parallel to rocket vel. vector

      raw_data[10] = baro.getPressure()/100;

      MS.read(); 
      raw_data[11] = MS.getPressurePascal();


    //Gather data again for integration (very ugly will be changed in the future)
      unsigned long t1 = millis(); //get time before each sampling

      accel.getEvent(&event);
      raw_data[0+15] = event.acceleration.x;
      raw_data[1+15] = event.acceleration.y;
      raw_data[2+15] = event.acceleration.z;

      kxAccel.getAccelData(&kxData); //Read KX134
      raw_data[3+15] = kxData.xData;
      raw_data[4+15] = kxData.yData;
      raw_data[5+15] = kxData.zData;
      
      IMU.getAGT(); //Read ICM
      raw_data[6+15] = IMU.accX();
      raw_data[7+15] = IMU.accY();
      raw_data[8+15] = IMU.accZ();
      raw_data[9+15] = IMU.gyrZ(); //z-Axis should be parallel to rocket vel. vector


      unsigned long deltaT = t2 - t1;

      for(int i=0; i<10; i++) {  //integrate using trapezoidal rule which states: Integral += (sample1 + sample2) * 0.5 * deltaT
        conv[i] += (raw_data[i] + raw_data[i+15])* 0.5 * deltaT; 
        data[17] = conv[9];
      } 
      velX = (conv[0] + conv[3] + conv[6])/3;
      velY = (conv[1] + conv[4] + conv[7])/3;
      velZ = (conv[2] + conv[5] + conv[8])/3;

      data[16] = velX;
      data[17] = velY;
      data[18] = velZ;

      vel = sqrt(velX*velX + velY*velY + velZ*velZ);

      velZ_abs = vel * sin(conv[9]); //Is angle in degrees or radiants? -> CHECK!!!!!!!


      alt1[k] += velZ_abs * deltaT; //integrates velocity to altitude

      mpl_alt = 288.15/0.0065 * (1 - pow(raw_data[10]/p0, 1/5.255)); //altitude according to barometric height (using standard atmosphere temps -> maybe should be changed)
      ms_alt =  288.15/0.0065 * (1 - pow(raw_data[11]/p0, 1/5.255));
      
      alt1[k+10] = (mpl_alt * ms_alt)/2;

      alt += alt1[k] + alt1[k+10]; //variable to have sum of all altitudes

      alt2 = alt/20; //average of last ten iterations of height (20 altitude datapoints -> 10 from accel, 10 from pressure)

      data[21] = (raw_data[10] + raw_data[11])/2;
      data[22] = alt2;
    }

    for(int i=0; i<12; i++) {
      data[i] = raw_data[i]; //copy raw data to send array
    }


    data[13] = (raw_data[0] + raw_data[3] + raw_data[6])/3; //avg of AccelX
    data[14] = (raw_data[1] + raw_data[4] + raw_data[7])/3; //avg of AccelY
    data[15] = (raw_data[2] + raw_data[5] + raw_data[8])/3; //avg of AccelZ

    data[12] = status;


    for(int i=0; i<23; i++) 
      Serial2.write(data[i]);


    if(data[13] > 5) {//5 referring to 5 m/s^2
      status = 0x04;
      start = millis();
      break;
    }
  }
}

void In_Flight_Loop() {

  SLAVE.onReceive(cmdFunc);

  float raw_data[14] = {0};
  float data[8] = {0};
  float alt_sum = 0;
  float vel_sum = 0;
  float acc_sum = 0;
  int i = 0;
  for(int j = 0, j < 10; j++) {
    while (Serial2.available()) //fill raw_data array with received data
    {
    raw_data[i] = Serial2.read();
    i++;
    }

    unsigned long deltaT = raw_data[13] - raw_data[6];

    //get total angle to z-axis
      float z_angle =+ (raw_data[1] + raw_data[8]) * 0.5 * deltaT; //integrate using trapezoidal rule which states: Integral += (sample1 + sample2) * 0.5 * deltaT
    
    float z_acc1 = raw_data[0] * sin(z_angle); //get absolute z-acceleration
    float z_acc2 = raw_data[7] * sin(z_angle); 
    acc_sum =+ z_acc1 + z_acc2;
    
  
    float z_vel =+ (z_acc1 + z_acc2) * 0.5 * deltaT;
    vel_sum =+ z_vel; //sum of 10 different vel values for moving avg

    float alt1 = z_vel * deltaT;
    float alt2 = 288.15/0.0065 * (1 - pow(raw_data[2]/p0, 1/5.255)); //altitude according to barometric height (using standard atmosphere temps -> maybe should be changed)
    float alt3 = 288.15/0.0065 * (1 - pow(raw_data[3]/p0, 1/5.255));
    float alt4 = 288.15/0.0065 * (1 - pow(raw_data[4]/p0, 1/5.255));
    float alt5 = 288.15/0.0065 * (1 - pow(raw_data[5]/p0, 1/5.255));

    alt_sum =+ alt1 + alt2 + alt3+ alt4+ alt5; //sum of 10 different alt values for moving avg
  } 

  float alt =+ (alt_sum/50); //avg of 50 altitude datapoints
  float alt_old = alt;
  float vel = vel_sum/10;
  float acc = acc_sum/20;
  float acc_old = acc;

  if(acc < 0 && status == 0x04) //burnout detected?
    status = 0x05;
  
  unsigned long now = millis();
  boolean timer = false;
  boolean drogue = false;

  if(alt_old - alt < 0 && vel < 0 && status == 0x05) //if altitude difference is negative and velocity is negative
    status = 0x06;
  else if ((now-start) > TIMERSETPOINT)
  {
    timer = true;
  }
  else if(cmd = 'q')
    drogue = true;

  if(status == 0x06 || timer == true || drogue == true) {
    digitalWrite(41, HIGH);
    delay(300);
    digitalWrite(41, LOW);
    status = 0x08
  }

  if(alt < mainSetPoint && status == 0x08) {
    digitalWrite(42, HIGH);
    delay(300);
    digitalWrite(42, LOW);
    status = 0x10;
  }
   
  if((acc - acc_old) < 1 && (alt - alt_old) < 2){
    status = 0x13
    break;
  }
    
  
}

void loop() {
  
}

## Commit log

2026-09-20 Finished sensor tables
    [Sensor Characteristics.xlsx]
2026-09-20 Restructured Theoretical part
    [Sensor Characteristics.xlsx]
2026-10-21 Added I2C communication chapter
2026-10-21 Added sources and citation for I2C theory part
2026-10-28 Added Schmitt-Trigger and RC circuit theory
2026-11-01 Added IMU and microcontroller evaluation
2026-11-01 Added accelerometer selection
2026-11-02 Added pressure sensor selection
2026-11-04 Added MOSFET and Zener Diode theory

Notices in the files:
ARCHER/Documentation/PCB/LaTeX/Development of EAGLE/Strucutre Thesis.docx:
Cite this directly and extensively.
